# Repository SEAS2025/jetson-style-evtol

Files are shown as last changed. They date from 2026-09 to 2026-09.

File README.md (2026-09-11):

# SEAS Solo-1

Single-seat electric octocopter targeting **FAA 14 CFR Part 103** (≤254 lb / 115 kg
empty, ≤55 kt level speed, one occupant), ~20 min endurance, 210 kg MTOW.
Airframe from **Aircraft Spruce** carbon tube; propulsion **T-MOTOR X-A12XL**
with a 13.5 kWh pack.

> Research and design study, not a flight-cleared design. Nothing here has been
> structurally tested. Read `docs/` before drawing conclusions.

## How this repo is wired

`design/params.py` is the single source of truth. The general-arrangement
drawing takes its dimension text from it and the CAD takes its geometry from
it, so the drawing cannot drift away from the model. `design/verify.py` then
loads the exported STL and asserts its bounding box back against those
parameters — if geometry and drawing ever disagree, the build fails.

```bash
python3 -m venv .venv && .venv/bin/pip install -r requirements.txt
bash scripts/build_all.sh
```

| Output | What it is |
| --- | --- |
| `output/views/solo1_general_arrangement.png` | Third-angle GA drawing, all views at 1:20 |
| `output/cad/solo1_frame_assembly.{step,stl}` | Spaceframe |
| `output/cad/cab_shell.{step,stl}` | Printed cockpit cab |
| `docs/BOM.md` | Aircraft Spruce part numbers |
| `docs/PROPULSION.md` | Mass budget and motor selection |

## The printed cab

A one-piece-per-segment PETG shell that replaces both the pod skin and the
roll hoop. It is **not primary structure**: Aircraft Spruce carbon tubes slide
into moulded interfaces and carry every flight load. PETG interlayer adhesion
is about 39% of in-plane strength, and EASA CM-S-008 treats polymer additive
manufacturing as suitable only for low-criticality parts, so the print is an
aerodynamic fairing plus seat support.

Shape follows a **Schempp-Hirth** high-performance sailplane forward fuselage:
fine nose entry, egg-shaped sections with the wide lobe down, maximum width at
the shoulders, contracting tailcone. Sections are held inside the 0.72–0.78
width-to-height band measured across the Discus a/b, Ventus-2a and a scaled
Radespiel ASW 19 survey. Real sailplane fuselages are taller than wide, which
is the opposite of most fairing intuition.

Run the pre-loft checks before touching geometry:

```bash
PYTHONPATH=. .venv/bin/python -m design.cab_check   # pilot fit, rotor clearance, bond, print volume
PYTHONPATH=. .venv/bin/python -m design.cab_cad     # loft the shell (~15 s for the loft alone)
```

### Things that are easy to get wrong

- **Aircraft Spruce indexes its carbon tube table by *inside* diameter, not
  outside.** A "1 inch" tube is a 1.000″ bore with a 0.120″ wall, so the real
  OD is 1.240″. Sockets modelled at 1.000″ would fit nothing. `SPRUCE_TUBES`
  derives OD as ID + 2×wall for this reason.
- **Do not infill the cab.** It encloses ~510 litres, so even 9% gyroid
  through that volume is ~58 kg of PETG — heavier than the entire airframe
  allowance. It prints as a hollow shell at zero infill, with solid material
  only in socket bosses and flange pads. Skin-only mass is 9.15 kg.
- **Tube interfaces are through-bores, not opposing blind sockets.** A rigid
  tube cannot enter two sockets that face each other, and the requirement is
  to slide members in after printing.
- **Loft sections must be single spline edges.** A smooth loft through
  polyline wires makes OCC solve a surface per edge per section and
  effectively never returns at this section count.
- **The Tronxy VEHO 1000-20 is 1000 × 1000 × 2000 mm** — the "-20" suffix is
  the Z height, not the model year. Z is capped to 600 mm per part here by
  choice, because that axis has the worst tramming drift and this machine
  family has a poor reliability record.

## Current state

Passing: rotor-disk clearance along the whole cab, reclined pilot fit to the
MIL-STD-1472G 50 mm floor, section ratio against published sailplane sections,
12-part segmentation inside the build volume, and bonded socket engagement
sized for the CS-22.561 9 g case with Hysol EA 9430.

Known and deliberate: fineness ratio is 3.19 against a Discus-class 9.5, and
the maximum section sits at 64% of length against Radespiel's measured 24%.
Both are artefacts of a truncated pod with no tailboom. The aft body will
separate without a tail fairing. Printed seams also stand proud of the 0.75 mm
laminar trip height, so treat the surface as fully turbulent.

### Next

1. Split the lofted shell into the 12 print parts and export a plate layout.
2. `docs/CAB.md` — print settings, tube BOM, assembly and bonding sequence.
3. Regenerate the GA drawing: the cab crown at z 1150 replaces the roll hoop,
   taking overall height 1120 → 1150 and length 2700 → 2750.

## Design parameters

Airframe: `design/params.py`. Cab: `design/cab_params.py`. Tube catalog:
`design/spruce_catalog.py`. Edit, re-run the checks, then rebuild.

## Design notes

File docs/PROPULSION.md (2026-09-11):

# SEAS Solo-1 — Propulsion (FAA Part 103)

**Regulatory target:** [14 CFR Part 103](https://www.ecfr.gov/current/title-14/chapter-I/subchapter-F/part-103) ultralight vehicle.

| Part 103 rule | Solo-1 design |
|---|---|
| Single occupant | Yes |
| Max empty weight **254 lb (115 kg)** | **115 kg** incl. batteries |
| Max speed **55 kt** | Software cap **102 km/h** |
| No night / IFR | Day VFR only |

**Endurance:** ~**20 min** at this mass budget (same class as Jetson ONE). **45 min is not compatible with Part 103** without a wing or hybrid — battery mass alone would exceed 254 lb empty.

Aircraft Spruce = airframe. Propulsion = below.

---

## Frozen Part 103 configuration

### 1. Propulsion — **4× T-MOTOR X-A12XL II-24S** (coaxial arm kits)

| Field | Value |
|---|---|
| Supplier | **T-MOTOR** |
| Part | **X-A12XL II-24S** Coaxial UAV Propulsion System |
| Qty | **4** (8 motors, 8× 120A ESC, props included) |
| Rated thrust | **28–34 kg/arm** (coaxial pair) |
| Coaxial quad MTOW | **~120 kg** published — **verify hover margin at 210 kg** with T-MOTOR before flight |
| Voltage | **20–24S** — spec **14S–16S pack** or **two 7S** split (match ESC voltage rating; confirm with T-MOTOR for 210 kg) |
| Arm tube | **50 mm** |
| Price | ~$1,000 / arm |
| Order | [shop.tmotor.com/products/x-a12xl-v2-24s-coaxial-uav-propulsion-system](https://shop.tmotor.com/products/x-a12xl-v2-24s-coaxial-uav-propulsion-system) |
| Contact | onlinesales@tmotor.com · WhatsApp **+86 180 7928 0718** |

> **Important:** Published MTOW for X-A12XL quad is below 210 kg. Before manned flight, require **written thrust test at 52.5 kg/arm** (210/4) on a thrust stand, or step up to **X-A14-24S** only if empty weight can stay ≤ 115 kg (unlikely). Part 103 + 210 kg MTOW is **experimental** — Jetson ONE operates outside US Part 103 empty-weight rules in practice.

**If thrust insufficient:** lighter pilot, shorter flight, or accept non–Part-103 experimental category.

### 2. Battery — **1× ~13.5 kWh Danergy pack (Molicel P60C)**

| Field | Value |
|---|---|
| Supplier | **Danergy** |
| Cell | **Molicel INR-21700-P60C** |
| Energy | **13.5 kWh** nominal (**~11.5 kWh** usable) |
| Target mass | **≤ 38 kg** (to hold **115 kg** empty with ~32 kg airframe + ~45 kg propulsion) |
| Voltage | **14S** nominal (~50.4 V) — Jetson-class |
| Discharge | **≥ 150 A** continuous |
| BMS | Smart **CAN** bus |
| Order | [danenergy.com](https://www.danenergy.com/catalog/lithium-ion-battery-packs/) — quote **“Solo-1 Part 103: 13.5 kWh 14S P60C, ≤38 kg, 600×350×180 mm”** |

Reference module: [14S8P 2.42 kWh](https://www.danenergy.com/catalog/lithium-ion-battery-packs/premium-high-power-molicel-p60c-li-ion-battery-48000mah-50-4v-144a-max-tn14s8p-p60c) — scale config with integrator.

**Swappable packs (optional):** two **~6.75 kWh** modules if each stays under weight budget for solo carry.

### 3. ESCs

**Included in X-A12XL kits** (24S FOC 120A × 2 per arm).

Spares: [Hobbywing XRotor Pro H200A 24S](https://www.hobbywing.com/en/products/xrotor-pro-h200a-24s-foc) or [XC-ESC CH200 v2](https://www.xc-esc.com/product/ch200-v2-esc-controller/).

### 4. Flight controller

| Item | Spec |
|---|---|
| **Cube Orange** or **Pixhawk 6X** | ArduPilot |
| Speed limit | Set **WPNAV_SPEED** / motor governor to **≤ 55 kt** |
| Mixing | Coaxial octo frame |

### 5. Charging

| Item | Spec |
|---|---|
| Input | **240 V AC** |
| Time | **~1 hr** @ 13.5 kWh (Jetson-class) |
| Connector | Per Danergy / **Anderson SB50** |

---

## Part 103 mass budget (must not exceed 115 kg empty)

| Component | kg | Notes |
|---|-----|---|
| Aluminum spaceframe (Spruce) | 28 | Weigh every tube; drill lightening holes in gussets |
| 4× X-A12XL arm kits (w/ ESC) | 20 | ~5 kg/arm installed target |
| Battery pack | 38 | 13.5 kWh P60C — **largest line item** |
| Harness + BRS chute (Spruce) | 16 | Confirm chute minimum weight band |
| Avionics + wiring | 5 | Minimal harness |
| Props / guards (in kit) | 8 | Included in arm kit mass above |
| **Total empty** | **115** | **254 lb — Part 103 ceiling** |
| Pilot (max) | 95 | 210 kg MTOW |
| **MTOW** | **210** | |

Weigh aircraft **without pilot** before every annual check; add ballast chart in logbook.

---

## Energy budget (~20 min)

| Parameter | Value |
|---|---|
| Usable energy | 11.5 kWh |
| Average power | ~34 kW |
| Peak power | ~88 kW (short climb) |
| Flight time | **~20 min** mixed |

---

## Procurement summary (Part 103)

| Line | Supplier | Qty | Est. |
|---|---|-----|---|
| X-A12XL II-24S coaxial arm | T-MOTOR | 4 | ~$4,000 |
| 13.5 kWh 14S P60C pack | Danergy | 1 | ~$4,000–7,000 |
| Cube Orange | CubePilot | 1 | ~$1,500 |
| **Total propulsion** | | | **~$9,500–12,500** |

---

## What we dropped (45 min config)

| Removed | Reason |
|---|---|
| U15XL arms | Too heavy for 115 kg empty |
| 56 kWh dual packs | ~175 kg batteries alone |
| 310 kg MTOW | Exceeds Part 103 spirit and BRS sizing |

---

*Regenerate CAD: `bash scripts/build_all.sh` on aimainframe.*

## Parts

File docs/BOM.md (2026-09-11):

# SEAS Solo-1 — Bill of Materials

Concept single-seat coaxial octocopter, Jetson ONE–class envelope. **Primary airframe, hardware, harness, and parachute from [Aircraft Spruce & Specialty](https://www.aircraftspruce.com).** Propulsion and avionics are listed separately (not Spruce catalog).

Target: **FAA Part 103** — **≤115 kg (254 lb) empty** incl. batteries, **≤55 kt**, single seat, **~20 min** flight, **210 kg MTOW** max.

---

## A. Airframe tubing (6061-T6) — Aircraft Spruce

Order by foot: add dash length to part number (e.g. `03-38900-6` = 6 ft).

| Qty | Spruce P/N | Description | Used for | Est. length |
|-----|---|---|---|---|
| 4 | **03-38900** | 1 × 1 × 0.065 sq tube | Keel rails, arm booms | 6 ft each |
| 6 | **03-00009** | 3/4 × 3/4 × 0.049 sq tube | Cross members, battery tray, gusset stubs | 4 ft each |
| 2 | **03-00045** | 1-1/8 OD × 0.065 round tube | Roll hoop (cut/weld or splice) | 6 ft |
| 2 | **03-34400** | 0.930 OD × 0.065 round tube | Skid rails | 4 ft |

Links:
- [03-38900](https://www.aircraftspruce.com/catalog/pnpages/03-38900.php)
- [03-00009](https://www.aircraftspruce.com/catalog/pnpages/03-00009.php)
- [Square tubing index](https://www.aircraftspruce.com/catalog/mepages/alumtubing-sq.php)
- [Round tubing index](https://www.aircraftspruce.com/catalog/mepages/alumtubing-rd.php)

---

## B. Hardware — Aircraft Spruce

| Qty | Spruce P/N | Description | Application |
|-----|---|---|---|
| 16 | **05-17037** | McFarlane MCS1105-3 rod end, 10-32 ext | Motor mount / arm fold fittings |
| 8 | **04-03454** | Heim HF-3M rod end (surplus) | Alternate / jury strut |
| 120 | **AN3-6A** … **AN3-10A** | AN3 bolts (pick grip per joint) | Gussets, brackets |
| 120 | **MS21042-3** | Stop nut 10-32 | With AN3 |
| 240 | **AN960-10** | Flat washer for AN3 | Under bolt head + nut |
| 200 | **AN470AD4-5** | 1/8 in universal rivet (example) | Gusset plates — match length to grip |
| 8 | **AN4-6A** | 1/4-28 bolt | Harness mounts, parachute brackets |
| 8 | **MS21042-4** | Stop nut 1/4-28 | With AN4 |
| 16 | **AN960-416** | Washer for AN4 | Harness / chute |

Selectors:
- [AN bolts](https://www.aircraftspruce.com/catalog/stpages/anbolts.php)
- [MS21042 nuts](https://www.aircraftspruce.com/catalog/pnpages/MS21042-3.php)
- [AN960 washers](https://www.aircraftspruce.com/catalog/hapages/flatwashers.php)
- [Solid rivets AN470](https://www.aircraftspruce.com/catalog/mepages/solidrivets.php)

---

## C. Safety — Aircraft Spruce

| Qty | Spruce P/N | Description | Notes |
|-----|---|---|---|
| 1 | **13-01300** | Style No. 5 seat belt / harness set | 2 in webbing; 1/4 in attach bolt |
| 1 | **13-20942** | BRS Top VLS Genesis ultralight chute | Confirm weight band with BRS |
| 1 | — | Full-face helmet (pilot supplied) | Open cockpit |

- [13-01300 harness](https://www.aircraftspruce.com/catalog/appages/seatbelt5.php)
- [13-20942 parachute](https://www.aircraftspruce.com/catalog/pnpages/13-20942.php)

---

## D. Electrical (Spruce wire + external packs)

| Qty | Spruce P/N | Description | Notes |
|-----|---|---|---|
| 50 ft | **MIL-W-22759/32-12** | Wire 12 AWG (example) | Motor feeds — order exact AWG from [wire section](https://www.aircraftspruce.com/catalog/mepages/wire.php) |
| 100 ft | **MIL-W-22759/32-20** | Wire 20 AWG | Signal / CAN |
| 1 | **11-02600** (series) | Adel clamps / lacing | Secure harness to frame |
| 1 | — | Danergy ~13.5 kWh 14S pack | ≤38 kg — see `PROPULSION.md` |

---

## E. Propulsion (not Aircraft Spruce)

**Full sourcing guide:** `docs/PROPULSION.md`

### Frozen Part 103 configuration

| Qty | Supplier | Part | Description | Link |
|-----|---|---|---|---|
| 4 | **T-MOTOR** | **X-A12XL II-24S** | Coaxial arm: 2× motor + 2× 120A ESC + props | [shop.tmotor.com](https://shop.tmotor.com/products/x-a12xl-v2-24s-coaxial-uav-propulsion-system) |
| 1 | **Danergy** | Custom **13.5 kWh 14S P60C** | ≤38 kg, CAN BMS | [danenergy.com](https://www.danenergy.com/catalog/lithium-ion-battery-packs/) |
| 1 | **CubePilot** | Cube Orange | ArduPilot, **55 kt** speed limit | [cubepilot.org](https://cubepilot.org) |
| 1 | **Molicel** | INR-21700-P60C | Cell spec for pack builder | [molicel.com](https://www.molicel.com/inr-21700-p60c/) |

| Qty | Item | Spec |
|-----|---|---|
| 1 | 4-axis stick | Thrust / yaw / pitch / roll |
| 1 | Speed governor | Software ≤ **55 kt** (Part 103) |

See **`docs/PROPULSION.md`** for mass budget and thrust-margin notes.

---

## F. Consumables & shop

| Item | Source |
|---|---|
| 6061 gusset sheet 0.063 in | Spruce aluminum sheet section |
| 4043 TIG rod | Spruce welding |
| Epoxy (carbon knee braces) | Spruce composites |
| Cherry/Avdel rivets if used | Spruce rivet section |

---

## Weight summary (Part 103 — 254 lb empty cap)

| Component | kg |
|---|-----|
| Airframe (aluminum) | 28 |
| Harness + chute | 16 |
| Battery (~13.5 kWh P60C) | 38 |
| 4× X-A12XL arm kits | 20 |
| Avionics + wiring | 5 |
| Props / guards (in kits) | 8 |
| **Empty (with batteries)** | **115** (max) |
| Pilot (max) | 95 |
| **MTOW** | **210** |

---

*Verify every Spruce P/N, length suffix, and price at order time. This is a concept homebuilt — not a type-certified design.*

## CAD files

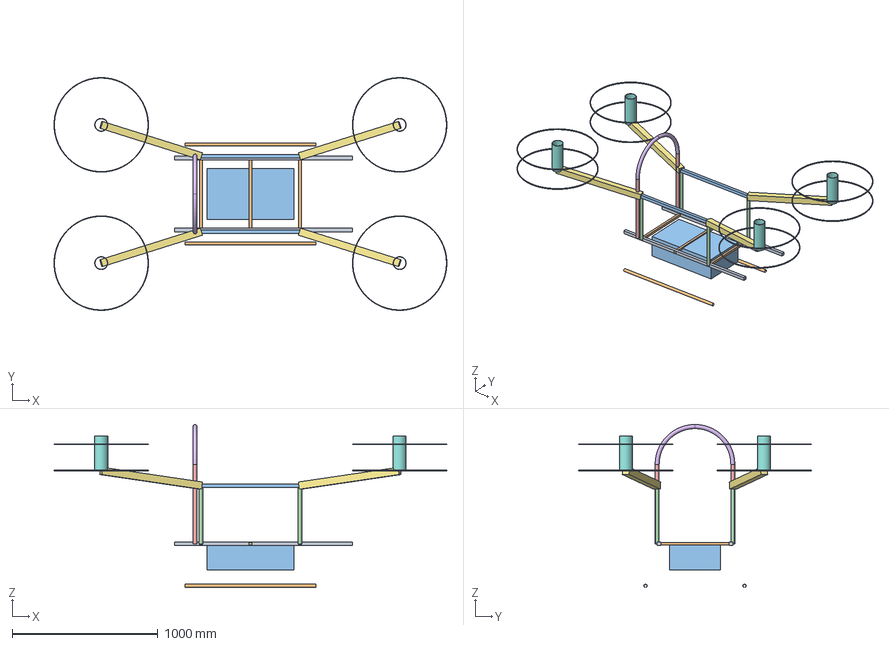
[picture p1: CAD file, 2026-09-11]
output/cad/solo1_frame_assembly.step
2699.4 x 1599.7 x 1120.0 mm
keel_-247
keel_247
frame_-340
frame_0
frame_340
upper_rail_-260
post_-340_-260
post_340_-260
upper_rail_260
post_-340_260
post_340_260
hoop_post_-260
hoop_post_260
hoop_crown
boom_0
mast_0
rotor_0_0
rotor_0_1
boom_1
mast_1
rotor_1_0
rotor_1_1
boom_2
mast_2
rotor_2_0
rotor_2_1
boom_3
mast_3
rotor_3_0
rotor_3_1
skid_-1
skid_1
battery_bay

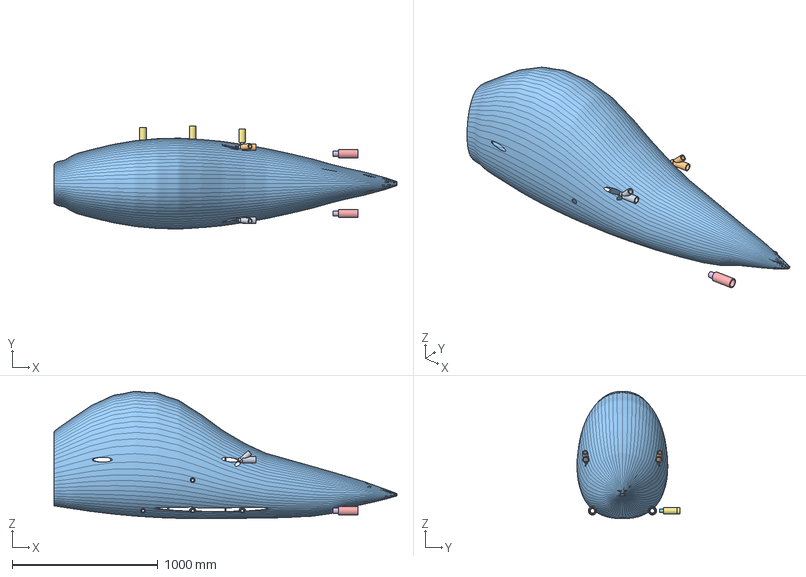
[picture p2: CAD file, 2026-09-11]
output/cad/cab_shell.step
2350.0 x 705.6 x 872.4 mm

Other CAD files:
output/cad/cab_shell.stl
output/cad/solo1_frame_assembly.stl

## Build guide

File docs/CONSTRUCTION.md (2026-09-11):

# SEAS Solo-1 — Construction Instructions

Coaxial octocopter, **FAA Part 103** ultralight (**≤115 kg empty**, **~20 min**). **All primary structure uses Aircraft Spruce 6061-T6 tube and AN/MS hardware** (see `BOM.md`). Propulsion: **4× T-MOTOR X-A12XL** + **13.5 kWh Danergy pack** (`PROPULSION.md`).

## Tools required

- Tube notcher or milling fixture for 1 in / 3/4 in square tube
- TIG welder (4043 filler) or bolted gusset construction
- Rivet gun (AN470) or AN3 bolted gussets
- Drill press, deburr, cleco kit
- Torque wrench for AN3/AN4
- Blender/CAD prints in `output/views/` for alignment

## Phase 1 — Cockpit safety cell

1. **Cut keel rails** from **03-38900** (1 × 1 × 0.065): two lengths ~1.5 m, parallel, spaced **COCKPIT_W** (520 mm) apart.
2. **Cross members** from **03-00009**: three rings at fore, mid, aft cockpit — square-cut, fish-mouth or gusset into keels.
3. **Roll hoop** from **03-00045**: bend to arc (≈ 600 mm ID), weld or sleeve-splice at base; mount to forward cross member with **AN4-6A** + **AN960-416** + **MS21042-4**.
4. Mount **13-01300** harness to hoop and aft cross member (1/4 in attach bolts per Spruce).
5. Install **13-20942** BRS top mount per BRS template — forward of pilot, clear prop disk.

## Phase 2 — Arm hardpoints

1. Fabricate four arm sockets from 1 in sq tube stubs welded to keels at **45°, 135°, 225°, 315°**.
2. **Arm booms** (03-38900): length **ARM_SPAN** (~720 mm), slight dihedral (**8°**).
3. At inboard end: **05-17037** rod end (MCS1105-3) for fold hinge — pin with **AN3** bolt + **MS21042-3** + **AN960-10**.
4. At outboard end: motor plate (aluminum gusset 0.063 sheet from Spruce) — two coax stacks separated **180 mm** vertically.

## Phase 3 — Motor / prop stack (per arm)

1. Upper and lower motor mounts tied with 3/4 in cross tube (**03-00009**).
2. Prop guard ring: carbon or aluminum — **650 mm** disk reference (see CAD).
3. Route **MIL-W-22759** motor leads along arm with Adel clamps; strain relief at hinge.

## Phase 4 — Landing gear

1. **Skids** from **03-34400**: two rails, **SKID_SPAN** 900 mm, splayed 15°.
2. Attach to keel with bolted gussets (AN3) — replaceable wear pads at ground contact.

## Phase 5 — Battery tray (Part 103 weight critical)

1. Single bay from **03-38900** + **03-00009** — ~**600 × 350 × 180 mm** (one **≤38 kg** Danergy 13.5 kWh module).
2. **Weigh empty aircraft** on scales after every structural change — must stay **≤ 115 kg (254 lb)** including battery.
3. Quick-release: 4× **AN4-6A** + **MS21042-4**; Anderson **SB50** or per Danergy spec.
4. CG: pack centered slightly forward of arm hub.

## Phase 6 — Systems

1. Flight computer and bus above battery tray; segregate power and signal harnesses.
2. 4-axis stick on right; arm/disarm interlock on left.
3. Ground test: motor sync, tilt stand, tethered hover before manned flight.

## Phase 7 — Fold (road trailer)

1. Arms fold upward using rod-end hinges; target folded width **980 mm** (props removed or hinged guards).
2. Pin each arm with **AN3** quick pins (Spruce pin section) for transport.

## Drawings

| View | File |
|---|---|
| Top | `output/views/solo1_top.png` |
| Side | `output/views/solo1_side.png` |
| Front | `output/views/solo1_front.png` |
| Isometric | `output/views/solo1_iso.png` |
| CAD STEP | `output/cad/solo1_frame_assembly.step` |
| CAD STL | `output/cad/solo1_frame_assembly.stl` |

Regenerate: `bash scripts/build_all.sh`

## Regulatory note

**14 CFR Part 103:** 254 lb empty, 55 kt max, single seat, day VFR. Set ArduPilot speed limit to **102 km/h**. Not FAA type certified. Weigh before flight. Thrust-test each arm at **≥52.5 kg** before manned ops (see `PROPULSION.md`).

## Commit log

2026-09-11 SEAS Solo-1: Part 103 octocopter airframe and printed sailplane-form cab
    Single source of truth in design/params.py drives both the general
    arrangement drawing and the CAD, with design/verify.py asserting the
    exported solid against the drawing so the two cannot silently diverge.
    The printed cab follows a Schempp-Hirth forward fuselage: egg sections
    held in the published 0.72-0.78 width-to-height band, carbon tube
    interfaces as through-bores so members slide in after printing, and
    pre-loft checks for pilot fit, rotor clearance, bond length and the
    Tronxy VEHO 1000-20 build volume.
    [cab_shell.step, cab_shell.stl, solo1_frame_assembly.step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]
2026-09-11 Document the design invariants and the traps that cost time
    Records the findings that are expensive to rediscover: the Spruce table is
    indexed by bore not OD, the cab must print at zero infill or the gyroid
    alone outweighs the airframe, tube interfaces must be through-bores, and
    loft sections must be single spline edges or OCC never returns.
